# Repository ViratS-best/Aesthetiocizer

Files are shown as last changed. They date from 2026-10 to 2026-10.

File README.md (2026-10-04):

# Aesthetiocizer

Voice-controlled car firmware and hardware design for the Seeed XIAO RP2040.
The firmware captures microphone audio, runs an Edge Impulse model, and uses
recognized commands to control the car.

## Design





## Commands

The firmware responds to classifications with confidence of at least 0.85:

- `drive` starts the motors.
- `stop` stops the motors.
- `music` plays a melody through the speaker.
- `lights` flashes the LEDs.

## Project Contents

- `example-standalone-inferencing-pico-main/example-standalone-inferencing-pico-main/` contains the Pico application and its Edge Impulse inference sources.
- `viratsuper6-project-1-cpp-mcu-v1-impulse-#1/` contains the exported Edge Impulse model and inference SDK files.
- `design/` contains the KiCad schematic, PCB, project, and 3D board export.
- `Screenshot *.png` files show project images.

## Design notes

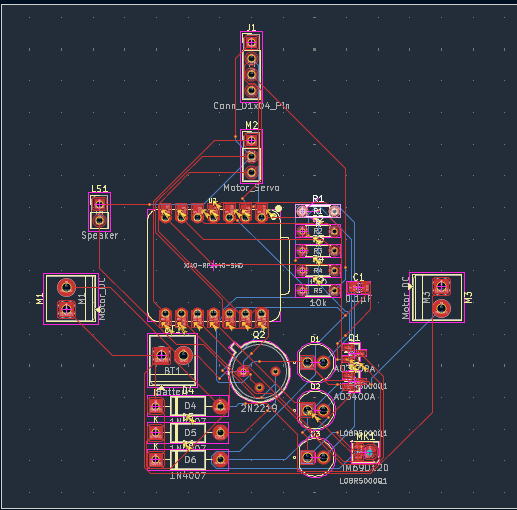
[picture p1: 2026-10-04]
Screenshot 2026-10-04 093300.png

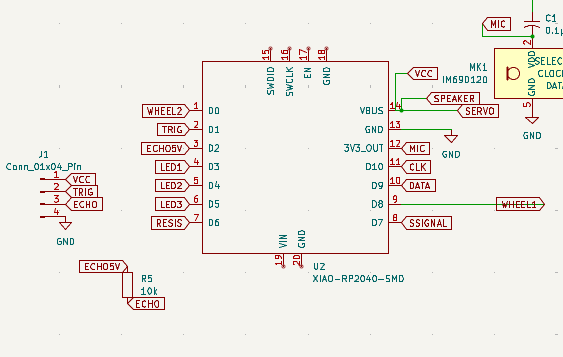
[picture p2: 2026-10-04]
Screenshot 2026-10-04 085456.png

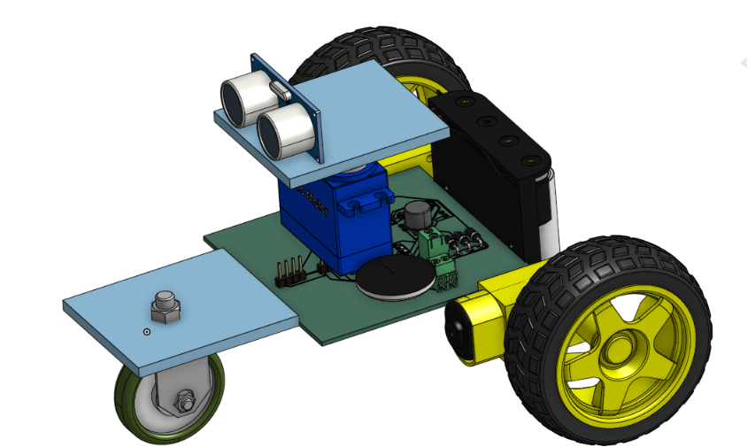
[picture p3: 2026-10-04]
Screenshot 2026-10-04 105420.png

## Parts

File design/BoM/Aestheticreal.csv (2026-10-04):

Reference | Qty | Value | DNP | Exclude from BOM | Exclude from Board | Exclude from Simulation | Exclude from Position Files | Footprint | Datasheet
BT1 | 1 | Battery |  |  |  |  | ${EXCLUDE_FROM_POS_FILES} | TerminalBlock_Phoenix:TerminalBlock_Phoenix_PT-1,5-2-3.5-H_1x02_P3.50mm_Horizontal
C1 | 1 | 0.1 |  |  |  |  | ${EXCLUDE_FROM_POS_FILES} | Capacitor_SMD:C_0805_2012Metric_Pad1.18x1.45mm_HandSolder
D1,D2,D3 | 3 | L08R5000Q1 |  |  |  |  | ${EXCLUDE_FROM_POS_FILES} | LEDRD:LEDRD254W57D500H1070
D4,D5,D6 | 3 | 1N4007 |  |  |  |  | ${EXCLUDE_FROM_POS_FILES} | Diode_THT:D_DO-41_SOD81_P10.16mm_Horizontal | http://www.vishay.com/docs/88503/1n4001.pdf
J1 | 1 | Conn_01x04_Pin |  |  |  |  | ${EXCLUDE_FROM_POS_FILES} | Connector_PinHeader_2.54mm:PinHeader_1x04_P2.54mm_Vertical
LS1 | 1 | Speaker |  |  |  |  | ${EXCLUDE_FROM_POS_FILES} | Connector_PinHeader_2.54mm:PinHeader_1x02_P2.54mm_Vertical
M1,M3 | 2 | Motor_DC |  |  |  |  | ${EXCLUDE_FROM_POS_FILES} | TerminalBlock_Phoenix:TerminalBlock_Phoenix_PT-1,5-2-3.5-H_1x02_P3.50mm_Horizontal
M2 | 1 | Motor_Servo |  |  |  |  | ${EXCLUDE_FROM_POS_FILES} | Connector_PinHeader_2.54mm:PinHeader_1x03_P2.54mm_Vertical | http://forums.parallax.com/uploads/attachments/46831/74481.png
MK1 | 1 | IM69D120 |  |  |  |  | ${EXCLUDE_FROM_POS_FILES} | Sensor_Audio:Infineon_PG-LLGA-5-1 | https://www.infineon.com/dgdl/Infineon-IM69D120-DS-v01_00-EN.pdf?fileId=5546d462602a9dc801607a0e41a01a2b
Q1,Q3 | 2 | AO3400A |  |  |  |  | ${EXCLUDE_FROM_POS_FILES} | Package_TO_SOT_SMD:SOT-23 | http://www.aosmd.com/pdfs/datasheet/AO3400A.pdf
Q2 | 1 | 2N2219 |  |  |  |  | ${EXCLUDE_FROM_POS_FILES} | Package_TO_SOT_THT:TO-39-3 | http://www.onsemi.com/pub_link/Collateral/2N2219-D.PDF
R1,R2,R3 | 3 | 220 |  |  |  |  | ${EXCLUDE_FROM_POS_FILES} | Resistor_THT:R_Axial_DIN0204_L3.6mm_D1.6mm_P5.08mm_Horizontal
R4 | 1 | 1000 |  |  |  |  | ${EXCLUDE_FROM_POS_FILES} | Resistor_THT:R_Axial_DIN0204_L3.6mm_D1.6mm_P5.08mm_Horizontal
R5 | 1 | 10000 |  |  |  |  | ${EXCLUDE_FROM_POS_FILES} | Resistor_THT:R_Axial_DIN0204_L3.6mm_D1.6mm_P5.08mm_Horizontal
U2 | 1 | XIAO-RP2040-SMD |  |  |  |  | ${EXCLUDE_FROM_POS_FILES} | XIAO:XIAO-RP2040-DIP

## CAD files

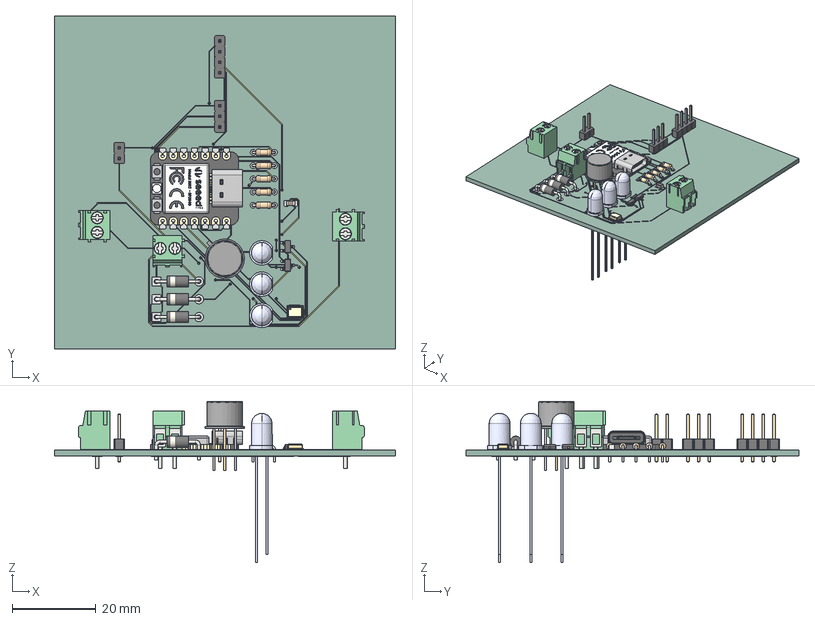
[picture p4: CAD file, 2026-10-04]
design/Aestheticreal.step
81.5 x 79.5 x 38.5 mm
SOT-23 x 2
TerminalBlock_Phoenix_PT-1,5-2-3.5-H_1x02_P3.50mm_Horizontal x 3
R_Axial_DIN0204_L36mm_D16mm_P508mm_Horizontal x 5
IM69D120V01XTSA1
PinHeader_1x03_P254mm_Vertical
Blue_LED_5mm_STEP x 3
PinHeader_1x02_P254mm_Vertical
TO-39-3
PinHeader_1x04_P254mm_Vertical
D_DO-41_SOD81_P10.16mm_Horizontal x 3
C_0805_2012Metric
type-c v2
smd_button v3
DOUT
DIN
VSS
VDD
smd_button v3(Mirror)
Aestheticreal_copper
Aestheticreal_pad
Aestheticreal_via
Aestheticreal_PCB

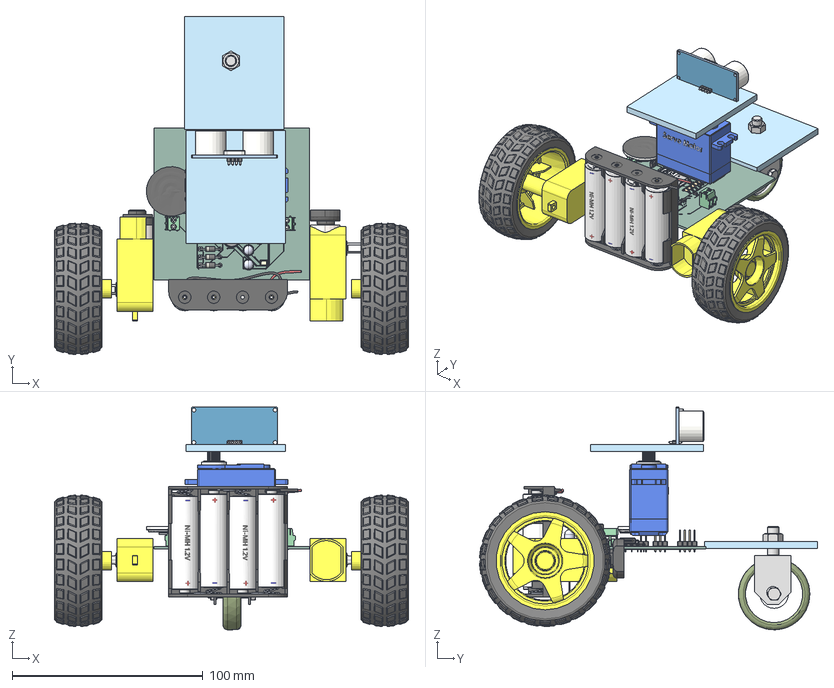
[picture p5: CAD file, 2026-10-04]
design/CAD/Aestheticreal 1.step
185.6 x 177.1 x 116.6 mm
Aestheticreal_copper x 66
Aestheticreal_pad x 189
Cut-Extrude8 x 2
type-c v2 x 24
IM69D120V01XTSA1 x 12
Aestheticreal_via x 29
D_DO-41_SOD81_P10.16mm_Horizontal
PinHeader_1x02_P254mm_Vertical
smd_button v3(Mirror)
PinHeader_1x04_P254mm_Vertical
R_Axial_DIN0204_L36mm_D16mm_P508mm_Horizontal_1
Split1[2] x 2
R_Axial_DIN0204_L36mm_D16mm_P508mm_Horizontal
Cut-Extrude7 x 2
PinHeader_1x03_P254mm_Vertical
TerminalBlock_Phoenix_PT-1,5-2-3.5-H_1x02_P3.50mm_Horizontal
TerminalBlock_Phoenix_PT-1,5-2-3.5-H_1x02_P3.50mm_Horizontal_1
TerminalBlock_Phoenix_PT-1,5-2-3.5-H_1x02_P3.50mm_Horizontal_2
Rim x 2
D_DO-41_SOD81_P10.16mm_Horizontal_2
C_0805_2012Metric
R_Axial_DIN0204_L36mm_D16mm_P508mm_Horizontal_3
Blue_LED_5mm_STEP_2
VDD
Tyre x 2
Blue_LED_5mm_STEP_1
VSS
SOT-23
Blue_LED_5mm_STEP
D_DO-41_SOD81_P10.16mm_Horizontal_1
smd_button v3
R_Axial_DIN0204_L36mm_D16mm_P508mm_Horizontal_4
TO-39-3
Aestheticreal_PCB
DOUT
DIN
BatteryPack4AA x 9
Ni-MHAABattery x 4
R_Axial_DIN0204_L36mm_D16mm_P508mm_Horizontal_2
SOT-23_1
ISO 4032 M12:1__Solid1
ISO 4032 M8:1__Solid1
ISO 4017 M8 x 45:1__Solid1
Tapak Roda:1__Solid1
Roda 3inch:1__Solid1
Shaft Roda:1__Solid1

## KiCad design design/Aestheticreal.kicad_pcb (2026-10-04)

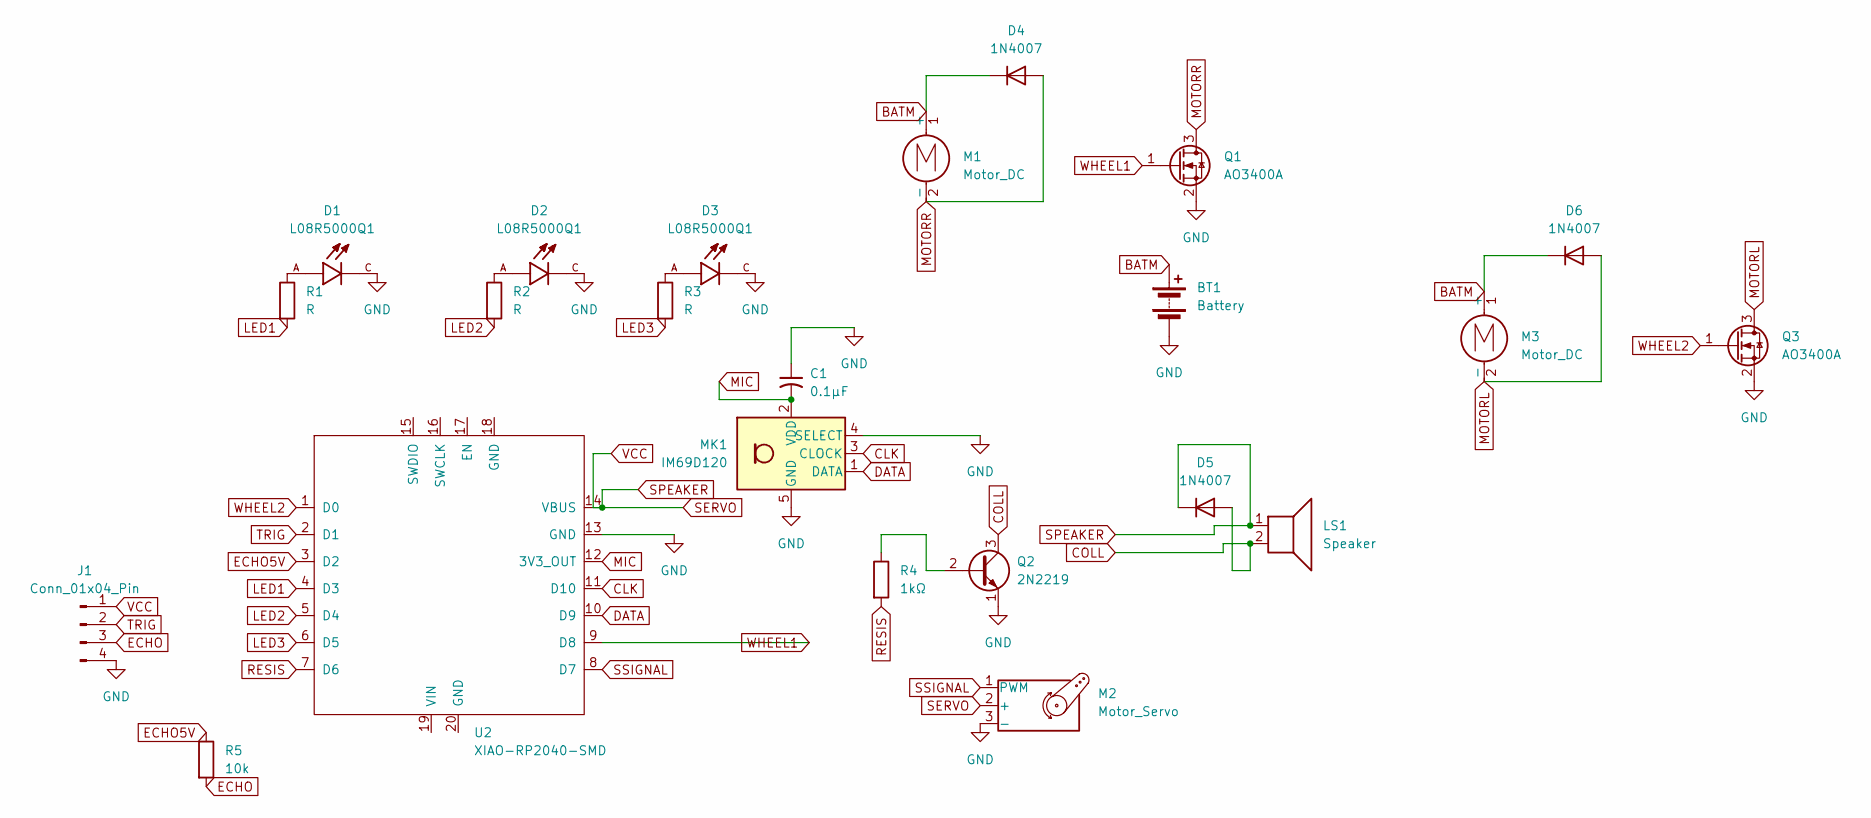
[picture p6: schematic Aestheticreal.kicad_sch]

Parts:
BT1: Battery; TerminalBlock_Phoenix_PT-1,5-2-3.5-H_1x02_P3.50mm_Horizontal
C1: 0.1µF; C_0805_2012Metric_Pad1.18x1.45mm_HandSolder
D1, D2, D3: L08R5000Q1; LEDRD254W57D500H1070; PARTREV NA
D4, D5, D6: 1N4007; D_DO-41_SOD81_P10.16mm_Horizontal
J1: Conn_01x04_Pin; PinHeader_1x04_P2.54mm_Vertical
LS1: Speaker; PinHeader_1x02_P2.54mm_Vertical
M1, M3: Motor_DC; TerminalBlock_Phoenix_PT-1,5-2-3.5-H_1x02_P3.50mm_Horizontal
M2: Motor_Servo; PinHeader_1x03_P2.54mm_Vertical
MK1: IM69D120; Infineon_PG-LLGA-5-1
Q1, Q3: AO3400A; SOT-23
Q2: 2N2219; TO-39-3
R1, R2, R3: R; R_Axial_DIN0204_L3.6mm_D1.6mm_P5.08mm_Horizontal
R4: 1kΩ; R_Axial_DIN0204_L3.6mm_D1.6mm_P5.08mm_Horizontal
R5: 10k; R_Axial_DIN0204_L3.6mm_D1.6mm_P5.08mm_Horizontal
U2: XIAO-RP2040-SMD; XIAO-RP2040-DIP

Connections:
BATM: BT1.1 (+), D4.1 (K), D6.1 (K), M1.1 (+), M3.1 (+)
CLK: MK1.3 (CLOCK), U2.11 (D10)
COLL: D5.2 (A), LS1.2, Q2.3 (C)
DATA: MK1.1 (DATA), U2.10 (D9)
ECHO: J1.3, R5.2
ECHO5V: R5.1, U2.3 (D2)
GND: BT1.2 (-), C1.1, D1.C, D2.C, D3.C, J1.4, M2.3 (-), MK1.4 (SELECT), MK1.5 (GND), Q1.2 (S), Q2.1 (E), Q3.2 (S), U2.13 (GND)
LED1: R1.2, U2.4 (D3)
LED2: R2.2, U2.5 (D4)
LED3: R3.2, U2.6 (D5)
MIC: C1.2, MK1.2 (VDD), U2.12 (3V3_OUT)
MOTORL: D6.2 (A), M3.2 (-), Q3.3 (D)
MOTORR: D4.2 (A), M1.2 (-), Q1.3 (D)
unnamed: D1.A, R1.1
unnamed: D2.A, R2.1
unnamed: D3.A, R3.1
unnamed: Q2.2 (B), R4.1
RESIS: R4.2, U2.7 (D6)
SERVO: D5.1 (K), J1.1, LS1.1, M2.2 (+), U2.14 (VBUS)
SSIGNAL: M2.1 (PWM), U2.8 (D7)
TRIG: J1.2, U2.2 (D1)
WHEEL1: Q1.1 (G), U2.9 (D8)
WHEEL2: Q3.1 (G), U2.1 (D0)

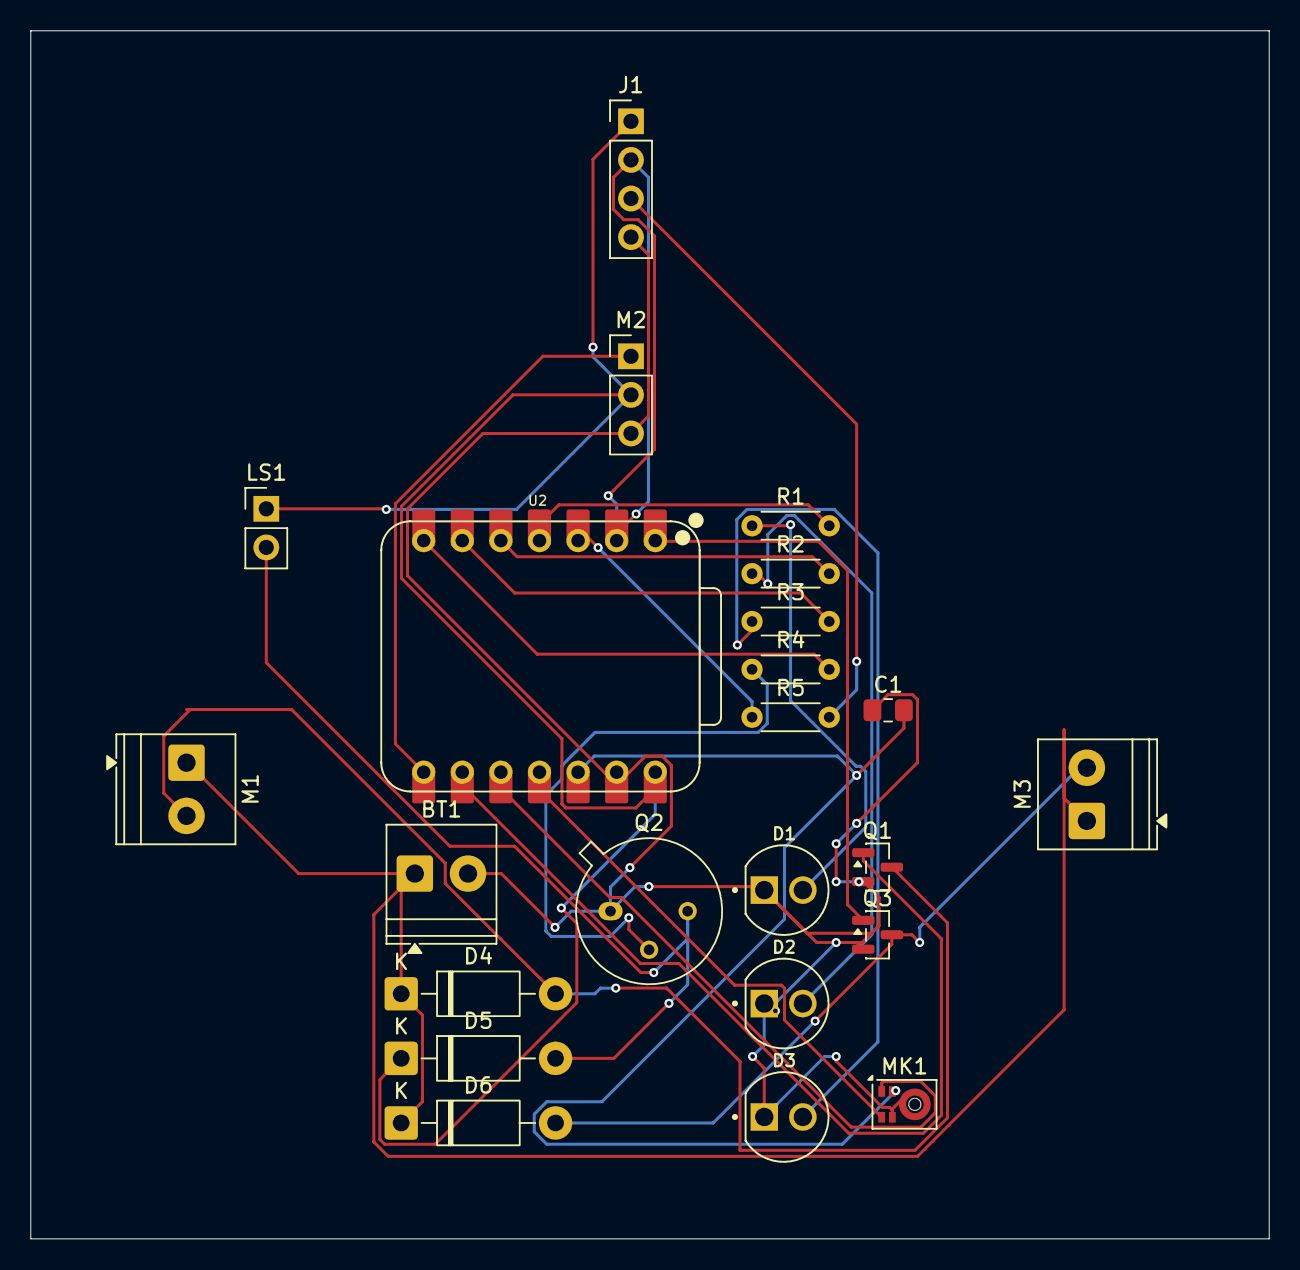
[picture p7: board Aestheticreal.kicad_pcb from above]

Board: 2 copper layers, 81.5 x 79.5 mm, 23 parts (0 on the bottom side), 23 nets.

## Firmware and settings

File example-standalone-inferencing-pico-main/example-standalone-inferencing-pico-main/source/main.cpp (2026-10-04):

#include "edge-impulse-sdk/classifier/ei_run_classifier.h"
#include "hardware/clocks.h"
#include "hardware/dma.h"
#include <hardware/gpio.h>
#include <hardware/pio.h>
#include <hardware/uart.h>
#include <hardware/pwm.h>
#include <pico/stdlib.h>
#include <pico/stdio_usb.h>
#include "pdm_microphone.pio.h"
#include <stdio.h>
#include <string.h>

const uint MOTOR_LEFT       = 26;
const uint ULTRASOUND_TRIG  = 27;
const uint ULTRASOUND_ECHO  = 28;
const uint LED1             = 29;
const uint LED2             = 6;
const uint LED3             = 7;
const uint SPEAKER          = 0;
const uint SERVO            = 1;
const uint MOTOR_RIGHT      = 2;
const uint MIC_DATA         = 4;
const uint MIC_CLOCK        = 3;
const uint SERVO_PWM_WRAP   = 39062;
static constexpr size_t PDM_DECIMATION = 64;
static constexpr size_t PDM_WORDS_PER_SAMPLE = PDM_DECIMATION / 32;
static constexpr size_t PDM_WORD_COUNT = EI_CLASSIFIER_RAW_SAMPLE_COUNT * PDM_WORDS_PER_SAMPLE;

union AudioCaptureBuffer {
    uint32_t pdm_words[PDM_WORD_COUNT];
    int16_t pcm_samples[EI_CLASSIFIER_RAW_SAMPLE_COUNT];
};

static AudioCaptureBuffer audio_buffer;
static size_t audio_slice_offset = 0;
static bool is_driving = false;

bool convert_pdm_to_pcm();
void play_rickroll();

#define NOTE_C4  262
#define NOTE_D4  294
#define NOTE_E4  330
#define NOTE_F4  349
#define NOTE_G4  392
#define NOTE_A4  440
#define NOTE_AS4 466
#define NOTE_B4  494
#define NOTE_C5  523
#define NOTE_D5  587
#define NOTE_E5  659

int melody[] = {
  NOTE_D4, NOTE_E4, NOTE_G4, NOTE_E4, NOTE_B4, NOTE_B4, NOTE_A4,
  NOTE_D4, NOTE_E4, NOTE_G4, NOTE_E4, NOTE_A4, NOTE_A4, NOTE_G4,
  NOTE_D4, NOTE_E4, NOTE_G4, NOTE_E4, NOTE_G4, NOTE_A4, NOTE_B4, NOTE_A4, NOTE_G4
};

int noteDurations[] = {
  8, 8, 8, 8, 4, 4, 2,
  8, 8, 8, 8, 4, 4, 2,
  8, 8, 8, 8, 4, 8, 8, 8, 2
};

int raw_feature_get_data(size_t offset, size_t length, float *out_ptr) {
    if (offset + length > EI_CLASSIFIER_SLICE_SIZE) {
        return -1;
    }
    for (size_t i = 0; i < length; i++) {
        out_ptr[i] = static_cast<float>(audio_buffer.pcm_samples[audio_slice_offset + offset + i]) / 32768.0f;
    }
    return 0;
}

bool capture_pdm_audio(PIO pio, uint sm, uint dma_channel) {
    pio_sm_set_enabled(pio, sm, false);
    pio_sm_clear_fifos(pio, sm);
    pio_sm_restart(pio, sm);
    pio_sm_clkdiv_restart(pio, sm);

    dma_channel_config dma_config = dma_channel_get_default_config(dma_channel);
    channel_config_set_transfer_data_size(&dma_config, DMA_SIZE_32);
    channel_config_set_read_increment(&dma_config, false);
    channel_config_set_write_increment(&dma_config, true);
    channel_config_set_dreq(&dma_config, pio_get_dreq(pio, sm, false));
    dma_channel_configure(
        dma_channel,
        &dma_config,
        audio_buffer.pdm_words,
        &pio->rxf[sm],
        PDM_WORD_COUNT,
        false
    );

    dma_start_channel_mask(1u << dma_channel);
    pio_sm_set_enabled(pio, sm, true);
    dma_channel_wait_for_finish_blocking(dma_channel);
    pio_sm_set_enabled(pio, sm, false);

    return convert_pdm_to_pcm();
}

bool convert_pdm_to_pcm() {
    uint32_t integrator1 = 0;
    uint32_t integrator2 = 0;
    uint32_t integrator3 = 0;
    uint32_t previous_integrator3 = 0;
    uint32_t previous_comb1 = 0;
    uint32_t previous_comb2 = 0;
    size_t pcm_index = 0;
    size_t decimation_count = 0;

    for (size_t word_index = 0; word_index < PDM_WORD_COUNT; word_index++) {
        uint32_t word = audio_buffer.pdm_words[word_index];
        for (int bit_index = 0; bit_index < 32; bit_index++) {
            int32_t bit = ((word >> bit_index) & 1u) ? 1 : -1;
            integrator1 += static_cast<uint32_t>(bit);
            integrator2 += integrator1;
            integrator3 += integrator2;

            if (++decimation_count == PDM_DECIMATION) {
                uint32_t comb1 = integrator3 - previous_integrator3;
                previous_integrator3 = integrator3;
                uint32_t comb2 = comb1 - previous_comb1;
                previous_comb1 = comb1;
                uint32_t comb3 = comb2 - previous_comb2;
                previous_comb2 = comb2;

                int64_t scaled = static_cast<int64_t>(static_cast<int32_t>(comb3)) * 32767 / 262144;
                if (scaled > 32767) scaled = 32767;
                if (scaled < -32768) scaled = -32768;
                audio_buffer.pcm_samples[pcm_index++] = static_cast<int16_t>(scaled);
                decimation_count = 0;
            }
        }
    }

    return pcm_index == EI_CLASSIFIER_RAW_SAMPLE_COUNT;
}

void handle_classifier_result(const ei_impulse_result_t& result) {
    for (uint16_t i = 0; i < EI_CLASSIFIER_LABEL_COUNT; i++) {
        float confidence = result.classification[i].value;
        const char* word = ei_classifier_inferencing_categories[i];
        printf("  %s: %.5f\n", word, confidence);

        if (confidence < 0.85f) {
            continue;
        }
        if (strcmp(word, "drive") == 0) {
            is_driving = true;
            gpio_put(LED1, 1);
        } else if (strcmp(word, "stop") == 0) {
            is_driving = false;
            gpio_put(MOTOR_LEFT, 0);
            gpio_put(MOTOR_RIGHT, 0);
            gpio_put(LED1, 0);
        } else if (strcmp(word, "music") == 0) {
            play_rickroll();
        } else if (strcmp(word, "lights") == 0) {
            gpio_put(LED1, 1);
            gpio_put(LED2, 1);
            gpio_put(LED3, 1);
            sleep_ms(500);
            gpio_put(LED1, 0);
            gpio_put(LED2, 0);
            gpio_put(LED3, 0);
        }
    }
}

bool initialize_microphone(PIO pio, uint sm, uint offset) {
    pio_gpio_init(pio, MIC_CLOCK);
    pio_gpio_init(pio, MIC_DATA);
    pio_sm_set_consecutive_pindirs(pio, sm, MIC_CLOCK, 1, true);
    pio_sm_set_consecutive_pindirs(pio, sm, MIC_DATA, 1, false);

    pio_sm_config config = pdm_microphone_program_get_default_config(offset);
    sm_config_set_sideset_pins(&config, MIC_CLOCK);
    sm_config_set_in_pins(&config, MIC_DATA);
    sm_config_set_in_shift(&config, true, true, 32);
    constexpr float PIO_CYCLES_PER_BIT = 4.0f + (1.0f / 32.0f);
    float divider = static_cast<float>(clock_get_hz(clk_sys)) /
        (EI_CLASSIFIER_FREQUENCY * PDM_DECIMATION * PIO_CYCLES_PER_BIT);
    sm_config_set_clkdiv(&config, divider);
    pio_sm_init(pio, sm, offset, &config);
    pio_sm_clear_fifos(pio, sm);
    return true;
}

void play_tone(uint pin, uint frequency, uint duration_ms) {
    if (frequency == 0) {
        sleep_ms(duration_ms);
        return;
    }
    uint period_us = 1000000 / frequency;
    uint pulse_us = period_us / 2;
    uint32_t cycles = (duration_ms * 1000) / period_us;
    
    for (uint32_t i = 0; i < cycles; i++) {
        gpio_put(pin, 1);
        sleep_us(pulse_us);
        gpio_put(pin, 0);
        sleep_us(pulse_us);
    }
}

void play_rickroll() {
    int totalNotes = sizeof(melody) / sizeof(melody[0]);
    for (int thisNote = 0; thisNote < totalNotes; thisNote++) {
        int noteDuration = 1000 / noteDurations[thisNote];
        play_tone(SPEAKER, melody[thisNote], noteDuration);
        sleep_ms(noteDuration * 0.30);
    }
}

float read_distance_cm() {
    gpio_put(ULTRASOUND_TRIG, 0);
    sleep_us(2);
    gpio_put(ULTRASOUND_TRIG, 1);
    sleep_us(10);
    gpio_put(ULTRASOUND_TRIG, 0);

    absolute_time_t timeout = make_timeout_time_us(30000);
    while (gpio_get(ULTRASOUND_ECHO) == 0) {
        if (time_reached(timeout)) {
            return -1.0f;
        }
        tight_loop_contents();
    }

    absolute_time_t start_time = get_absolute_time();
    timeout = make_timeout_time_us(30000);
    while (gpio_get(ULTRASOUND_ECHO) == 1) {
        if (time_reached(timeout)) {
            return -1.0f;
        }
        tight_loop_contents();
    }
    absolute_time_t end_time = get_absolute_time();

    int64_t pulse_duration = absolute_time_diff_us(start_time, end_time);
    float distance = (float)pulse_duration / 58.0f;
    return distance;
}

void set_servo_angle(uint pin, float angle) {
    if (angle < 0.0f) angle = 0.0f;
    if (angle > 180.0f) angle = 180.0f;
    float pulse_width_ms = 0.5f + (angle / 180.0f) * 2.0f;
    uint16_t level = static_cast<uint16_t>((pulse_width_ms / 20.0f) * (SERVO_PWM_WRAP + 1));
    pwm_set_gpio_level(pin, level);
}

int main() {
    stdio_usb_init();

    gpio_init(MOTOR_LEFT);
    gpio_set_dir(MOTOR_LEFT, GPIO_OUT);
    gpio_init(MOTOR_RIGHT);
    gpio_set_dir(MOTOR_RIGHT, GPIO_OUT);

    gpio_init(LED1); gpio_set_dir(LED1, GPIO_OUT);
    gpio_init(LED2); gpio_set_dir(LED2, GPIO_OUT);
    gpio_init(LED3); gpio_set_dir(LED3, GPIO_OUT);

    gpio_init(SPEAKER);
    gpio_set_dir(SPEAKER, GPIO_OUT);
    gpio_init(ULTRASOUND_TRIG);
    gpio_set_dir(ULTRASOUND_TRIG, GPIO_OUT);
    gpio_init(ULTRASOUND_ECHO);
    gpio_set_dir(ULTRASOUND_ECHO, GPIO_IN);

    gpio_set_function(SERVO, GPIO_FUNC_PWM);
    uint slice_num = pwm_gpio_to_slice_num(SERVO);
    pwm_config config = pwm_get_default_config();
    pwm_config_set_clkdiv(&config, 64.0f);
    pwm_config_set_wrap(&config, SERVO_PWM_WRAP);
    pwm_init(slice_num, &config, true);

    PIO microphone_pio = pio0;
    uint microphone_sm = pio_claim_unused_sm(microphone_pio, true);
    uint microphone_offset = pio_add_program(microphone_pio, &pdm_microphone_program);
    initialize_microphone(microphone_pio, microphone_sm, microphone_offset);
    uint microphone_dma = dma_claim_unused_channel(true);
    run_classifier_init();
    printf("PDM microphone ready: %u Hz, GPIO data %u, clock %u\n",
        EI_CLASSIFIER_FREQUENCY, MIC_DATA, MIC_CLOCK);
    ei_impulse_result_t result = {nullptr};

    while (true) {
        if (!capture_pdm_audio(microphone_pio, microphone_sm, microphone_dma)) {
            gpio_put(MOTOR_LEFT, 0);
            gpio_put(MOTOR_RIGHT, 0);
            printf("PDM conversion failed; motors stopped.\n");
            continue;
        }

        for (size_t slice = 0; slice < EI_CLASSIFIER_SLICES_PER_MODEL_WINDOW; slice++) {
            audio_slice_offset = slice * EI_CLASSIFIER_SLICE_SIZE;
            signal_t audio_signal;
            audio_signal.total_length = EI_CLASSIFIER_SLICE_SIZE;
            audio_signal.get_data = &raw_feature_get_data;

            EI_IMPULSE_ERROR res = run_classifier_continuous(&audio_signal, &result, false);
            if (res != EI_IMPULSE_OK) {
                printf("Classifier error: %d\n", res);
                continue;
            }

            printf("Timing: DSP %d ms, inference %d ms\n", result.timing.dsp, result.timing.classification);
            handle_classifier_result(result);
        }

        if (is_driving) {
            float distance_center = read_distance_cm();

            if (distance_center < 0.0f) {
                gpio_put(MOTOR_LEFT, 0);
                gpio_put(MOTOR_RIGHT, 0);
            } else if (distance_center > 20.0f) {
                gpio_put(MOTOR_LEFT, 1);
                gpio_put(MOTOR_RIGHT, 1);
            } else {
                gpio_put(MOTOR_LEFT, 0);
                gpio_put(MOTOR_RIGHT, 0);

                set_servo_angle(SERVO, 150.0f);
                sleep_ms(400);
                float left_dist = read_distance_cm();

                set_servo_angle(SERVO, 30.0f);
                sleep_ms(500);
                float right_dist = read_distance_cm();

                set_servo_angle(SERVO, 90.0f);
                sleep_ms(300);

                if (left_dist < 0.0f || right_dist < 0.0f) {
                    gpio_put(MOTOR_LEFT, 0);
                    gpio_put(MOTOR_RIGHT, 0);
                } else if (left_dist > right_dist) {
                    gpio_put(MOTOR_LEFT, 0);
                    gpio_put(MOTOR_RIGHT, 1);
                    sleep_ms(600);
                } else {
                    gpio_put(MOTOR_LEFT, 1);
                    gpio_put(MOTOR_RIGHT, 0);
                    sleep_ms(600);
                }
                
                gpio_put(MOTOR_LEFT, 0);
                gpio_put(MOTOR_RIGHT, 0);
            }
        }

    }
}

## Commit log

2026-10-04 Enhance README with PCB badge and images
    Added PCB badge link and images to the README.
2026-10-04 Add project README and manufacturing files
    [Aestheticreal 1.step, Aestheticreal.csv]
2026-10-17 Revise README for clarity and add BOM section
    Updated project description and contents for clarity. Added Bill of Materials section.
2026-10-17 BOM.csv added and removed Aestheticreal.csv
    Fixing for re-review
2026-10-18 Added KiCad files
2026-10-18 Add new photo of PCB
